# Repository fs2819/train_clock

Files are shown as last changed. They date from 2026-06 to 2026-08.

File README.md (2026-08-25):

# Analog Subway Clock

An analog clock whose hands show the time until the next downtown 1 train arrives at 125th Street (NYC MTA). Runs on a Raspberry Pi Zero 2 W.

## How It Works

The software recomputes hand positions every 10 seconds (`POLL_INTERVAL_SECONDS`), re-fetching the MTA's public GTFS-Realtime feed only when the cache has aged past 30 seconds (`CACHE_TTL_SECONDS`). Arrival times are absolute, so between fetches the hands keep counting down accurately from cached data. The fetch parses the protobuf response and extracts arrival predictions for the southbound 1 train at 125th St (GTFS stop `116S`). The minutes until arrival are mapped to positions on the clock face and driven by three independent stepper motors — one per hand, each following its own train (see *Hand assignment* below).

**Countdown mapping.** 12 o'clock represents a train arriving *now*. A hand for a train `m` minutes away sits `m` minutes *before* 12 — i.e. counterclockwise from the top, exactly like reading a normal clock backwards from the hour:

| Minutes to train | Hand position |
| --- | --- |
| 0 (arriving) | 12 o'clock |
| 1 | the "59" mark (just before 12) |
| 15 | 9 o'clock |
| 30 | 6 o'clock |
| 55 (capped) | 1 o'clock |

As a train approaches, its hand sweeps clockwise up toward 12. Trains beyond `CLOCK_MAX_MINUTES` (55) are pegged at the 1 o'clock cap so a far-out train never wraps past 12 and collides with the "arriving now" position.

**Each hand follows one train.** Hands are *not* pinned to "soonest / second /
third". A hand is handed a specific train (identified by its GTFS trip ID) and
tracks that same train all the way in, sweeping clockwise toward 12. When its
train arrives, that hand takes the soonest train no other hand is showing —
which, since the other two hands are holding the nearer trains, is the
furthest-out train on the dial. So the hand that just reached 12 recycles to
the back of the queue and the other two keep sweeping undisturbed, instead of
all three shuffling up a place on every arrival.

**Hands only ever turn clockwise.** The countdown mapping already sweeps a hand
clockwise as its train approaches, and when a hand switches trains it travels
clockwise to the new position too — the long way round the dial rather than
back-tracking. Over a day every hand rotates in one direction only, like a real
clock.

**Each hand re-homes when its train arrives.** Half-step slip is invisible on
any single move but accumulates over hours, so a clock homed only at startup
has hands well out of place by morning. Instead, the moment a hand's train
leaves the feed — and *before* it swings round to its next train — that one
hand re-homes on its magnet and starts the new sweep from a known 12 o'clock.
The other two hands are untouched and keep tracking their own trains. Homing
sweeps forward, so this respects the clockwise-only rule; the cost is up to one
extra lap (~12 s) that the hand was largely going to make anyway. Set
`REHOME_AFTER_ARRIVAL = False` in `config.py` to go back to homing only at
startup.

At startup all three hands home to 12 o'clock, then take the three soonest
trains by the shortest path (the clockwise-only rule applies to swapping
trains, not to first placement).

This is a Python translation of the [SubwayTimeService](../SubwayTimeService) Go project, stripped of AWS infrastructure (Lambda, DynamoDB, API Gateway) and adapted to run locally on the Pi.

## Project Structure

```
analog_clock/
  config.py             # Station, route, feed URL, polling, GPIO pins, geometry
  mta_feed.py           # Fetches + parses GTFS-Realtime protobuf from MTA
  subway_times.py       # Caching layer, computes minutes-to-arrival
  clock_controller.py   # Maps minutes -> hand angle, drives the 3 steppers
  stepper.py            # StepperHand: half-stepping, homing, position tracking
  main.py               # Entry point — poll loop
  requirements.txt      # Python dependencies
  # Hardware bring-up / diagnostics (run on the Pi):
  test_motor.py         # Spin one motor a full revolution each way
  test_hall.py          # Live readout of one hall sensor
  test_hall_live.py     # Live readout of all three hall sensors at once
```

When `MOTORS_ENABLED = False` (the default, for laptop development), `clock_controller`
just logs what each hand *would* do, so the whole app runs anywhere without GPIO.
Set it to `True` on the Pi to drive the motors.

## Setup (Local / Development)

```bash
# Install uv if you don't have it:
curl -LsSf https://astral.sh/uv/install.sh | sh

uv venv
source .venv/bin/activate
uv pip install -r requirements.txt
uv run main.py
```

No API key is needed — the MTA GTFS-Realtime endpoint is public.

## Deploying to Raspberry Pi Zero 2 W

### 1. OS Setup

Flash **Raspberry Pi OS Lite (64-bit)** onto a microSD card using [Raspberry Pi Imager](https://www.raspberrypi.com/software/). In the imager's settings:
- Enable SSH
- Set your Wi-Fi credentials
- Set a hostname (e.g., `subwayclock.local`)

### 2. SSH In and Install Dependencies

```bash
ssh pi@subwayclock.local

# Update system
sudo apt update && sudo apt upgrade -y

# Install uv
curl -LsSf https://astral.sh/uv/install.sh | sh

# Clone or copy your code to the Pi
# Option A: git clone
# Option B: scp -r analog_clock/ pi@subwayclock.local:~/analog_clock/

cd ~/analog_clock
uv venv
source .venv/bin/activate
uv pip install -r requirements.txt
```

### 3. Test It

```bash
uv run main.py
```

You should see log output like:
```
2026-06-29 23:38:30 [__main__] INFO: Analog subway clock starting
2026-06-29 23:38:30 [mta_feed] INFO: 1 train at 125th St arriving Mon Jun 29 23:48:25 EDT (9.8 min)
2026-06-29 23:38:30 [__main__] INFO: Next 3 trains (min): ['9.8', '21.0', '34.5']
```

With `MOTORS_ENABLED = True`, you'll also see the hands home on startup and then
each move to its train's position:
```
[clock_controller] INFO: Homing 3 hands sequentially...
[stepper] INFO: [hand1] home found (magnet zone 152 steps, centered, offset +0)
...
[clock_controller] INFO: [hand1] 9.8 min -> -58.8°
```

### 4. Run on Boot (systemd)

Create a service file:

```bash
sudo nano /etc/systemd/system/subwayclock.service
```

```ini
[Unit]
Description=Analog Subway Clock
After=network-online.target
Wants=network-online.target

[Service]
Type=simple
User=pi
WorkingDirectory=/home/pi/analog_clock
ExecStart=/home/pi/analog_clock/.venv/bin/python main.py
Restart=always
RestartSec=10

[Install]
WantedBy=multi-user.target
```

```bash
sudo systemctl enable subwayclock
sudo systemctl start subwayclock

# Check logs:
journalctl -u subwayclock -f
```

## Hardware

Three **28BYJ-48** stepper motors (one per hand), each driven by a **ULN2003**
board, plus three hall-effect sensors for homing. Everything runs at 5V/3.3V
directly off the Pi — no external driver chips.

### GPIO wiring (BCM numbering)

Each ULN2003 board: `+` → 5V, `−` → GND, IN1–IN4 → four GPIOs.
Each hall sensor: VCC → **3.3V** (not 5V — keeps the signal pin within the
GPIO's safe range), GND → GND, OUT → one GPIO.

| Hand | Position | IN1 | IN2 | IN3 | IN4 | Hall OUT |
| --- | --- | --- | --- | --- | --- | --- |
| 1 | bottom | GPIO6 | GPIO13 | GPIO19 | GPIO26 | GPIO4 |
| 2 | middle | GPIO12 | GPIO16 | GPIO20 | GPIO21 | GPIO5 |
| 3 | top | GPIO17 | GPIO27 | GPIO22 | GPIO23 | GPIO24 |

All pins are defined in `config.py` (the `HANDS` list) — change them there if you
rewire. Use the breadboard power rails to fan out 5V / 3.3V / GND, since the Pi
header doesn't have enough power pins for three boards plus three sensors. **All
grounds must be common.**

> **Power note.** All three boards share the Pi's 5V pin. To stay within budget,
> the firmware moves and homes **one motor at a time** (~250 mA peak). Don't
> drive all three simultaneously on this power setup, or the Pi can brown out.
> For simultaneous motion, feed the boards from an external 5V supply (grounds
> still tied to the Pi).

### Homing

Each hand carries a magnet; a fixed sensor in the top plate detects it at the
12 o'clock position. On startup — and again for each hand as its train arrives,
unless `REHOME_AFTER_ARRIVAL` is off — `StepperHand.home()`:

1. Sweeps until it finds the magnet's **trigger zone** (an arc, not a point).
2. Measures the zone width and parks at its **center** — the most repeatable
   reference — then applies an optional per-hand `home_offset_steps` fudge to
   land exactly on 12. Budget is two full revolutions, so a wide zone or a
   worst-case start position can never run out.

A re-home that fails mid-run (bad sensor read, magnet knocked loose) is logged
and skipped rather than raised: that hand carries on from its last known,
drifted position and the rest of the clock keeps running.

`HALL_ACTIVE_LEVEL` in `config.py` is the level the sensors read with a magnet
present. These modules are **active-HIGH** (read 1 with a magnet, idle 0).

### Geometry / calibration

- `STEPS_PER_REV = 8192` — **measured**, not assumed. On this hardware, 4096
  half-steps produced only 180° of output rotation, so a full revolution is
  8192. Every minutes→angle conversion depends on this; homing is sensor-based
  and unaffected. (~22.8 steps per degree.)
- `home_offset_steps` (per hand in `HANDS`) nudges that hand clockwise after
  homing to correct a magnet that isn't exactly at 12. The top hand uses -91
  (re-tuned for the current magnets); the others 0. Tune by eye.
- `STEP_DELAY_SECONDS = 0.0015` — the pause between issued half-steps, i.e.
  the speed limit. 1.5 ms works out to ~667 half-steps/s, so a full revolution
  takes `8192 x 0.0015` ≈ **12.3 s** (~5 rpm at the hand). Raised from 1.2 ms
  after the first overnight run drifted badly. This is the single
  most important number for drift: the 28BYJ-48 is driven **open-loop**, with
  no encoder and no acceleration ramp, so if the rotor can't keep up with the
  commanded field it slips poles silently — the code still believes it moved,
  and the hand is permanently offset until the next home. Slower = more torque
  margin. If drift is still building between re-homes, raise it further (up to
  ~2.0 ms) and accept longer sweeps; if a motor audibly buzzes without turning,
  it is already too fast.
- `MINUTES_PER_REV = 60`, `CLOCK_MAX_MINUTES = 55` — the countdown mapping (see
  *How It Works*).

### Bring-up procedure (on the Pi)

Stop the service first so it isn't holding the GPIO: `sudo systemctl stop subwayclock`.

```bash
.venv/bin/python test_motor.py 1      # spin each motor: 1, 2, 3
.venv/bin/python test_hall_live.py    # wave a magnet at each sensor, watch it flip
```

Then set `MOTORS_ENABLED = True` in `config.py`, run `.venv/bin/python main.py`
to watch it home and track trains, and finally `sudo systemctl start subwayclock`.

### GPIO dependencies on the Pi

`gpiozero` + `lgpio` come from apt, **not pip** (the lgpio wheel needs `swig` to
compile and fails under `uv`):

```bash
sudo apt install -y python3-gpiozero python3-lgpio
```

The venv must be able to see them, so create it with system site-packages:

```bash
uv venv --system-site-packages
```

(For an existing venv: set `include-system-site-packages = true` in
`.venv/pyvenv.cfg`.)

### Useful Resources

- `gpiozero` docs: https://gpiozero.readthedocs.io/
- MTA GTFS-Realtime reference: https://api.mta.info/
- Raspberry Pi GPIO pinout: https://pinout.xyz/

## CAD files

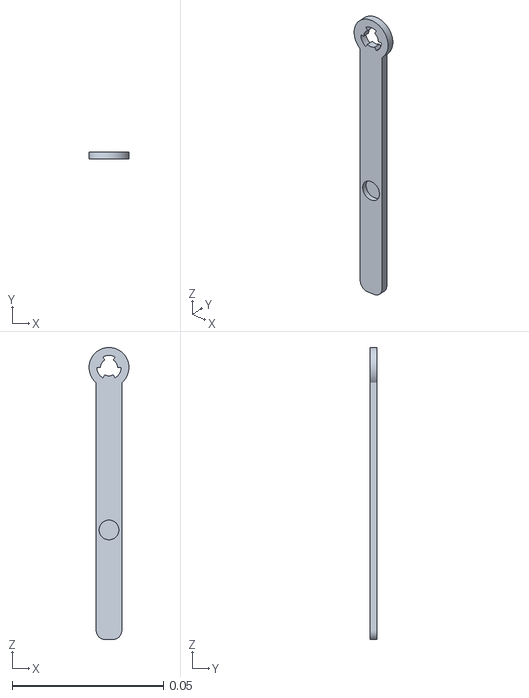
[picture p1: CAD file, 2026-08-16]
3d_printed_parts/Clock V3 Tall/Clock v3_tall - middle needle.stl
0.0132 x 0.0024 x 0.0966

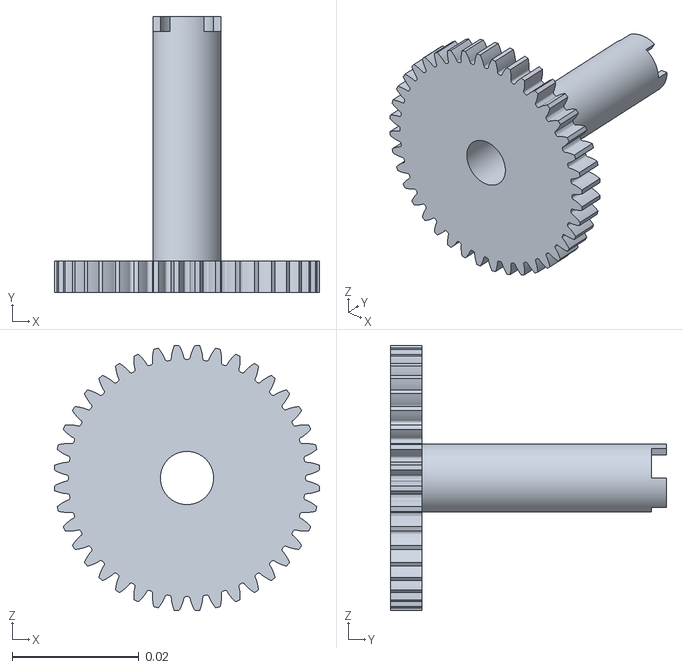
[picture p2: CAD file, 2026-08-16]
3d_printed_parts/Clock V3 Tall/Clock v3_tall - top gear.stl
0.0419 x 0.0436 x 0.0419

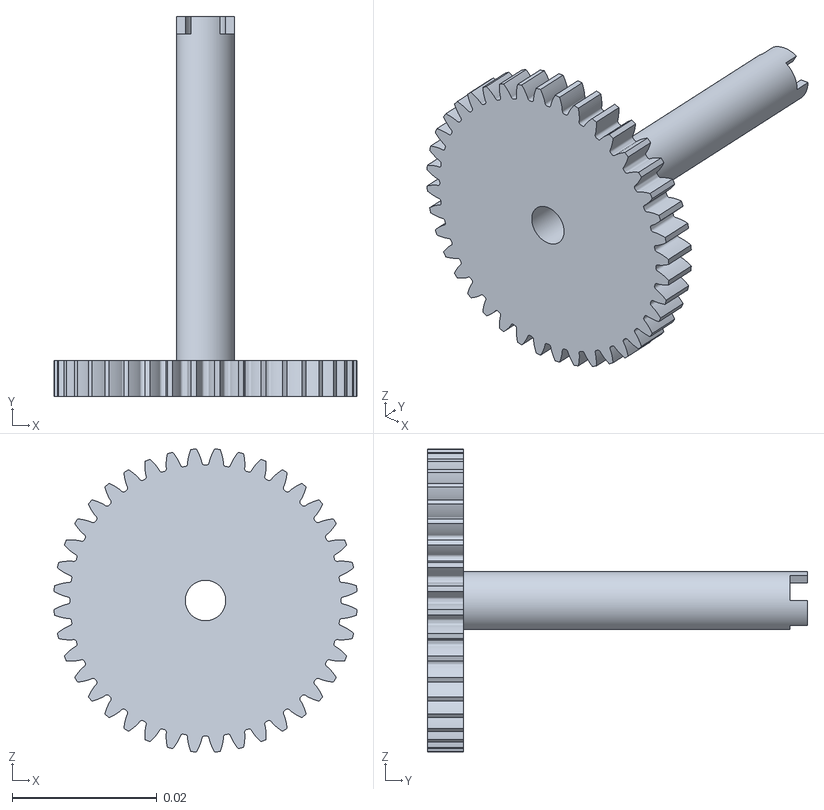
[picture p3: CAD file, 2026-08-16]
3d_printed_parts/Clock V3 Tall/Clock v3_tall - Middle gear.stl
0.0419 x 0.0526 x 0.0419

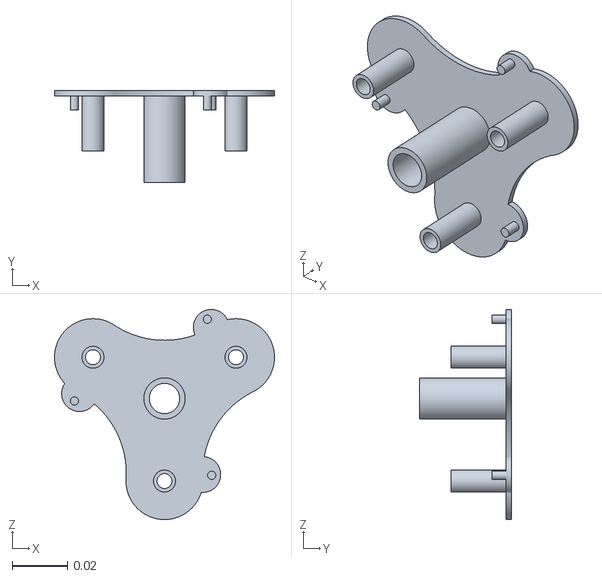
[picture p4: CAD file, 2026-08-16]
3d_printed_parts/Clock V3 Tall/Clock v3_tall - top plate.stl
0.08 x 0.0334 x 0.0764

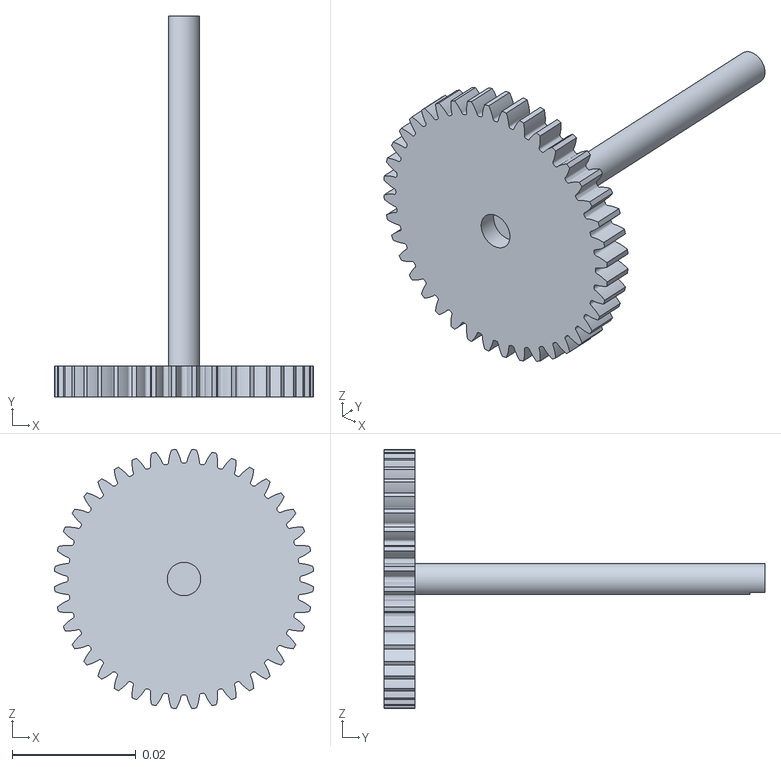
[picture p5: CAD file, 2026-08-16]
3d_printed_parts/Clock V3 Tall/Clock v3_tall - Bottom gear.stl
0.0419 x 0.0616 x 0.0419

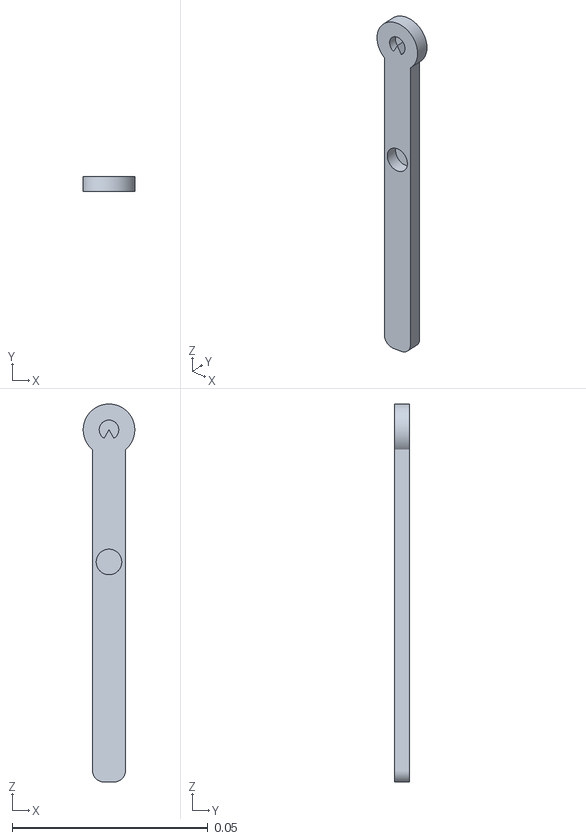
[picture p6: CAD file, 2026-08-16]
3d_printed_parts/Clock V3 Tall/Clock v3_tall - top needle.stl
0.0132 x 0.0039 x 0.0966

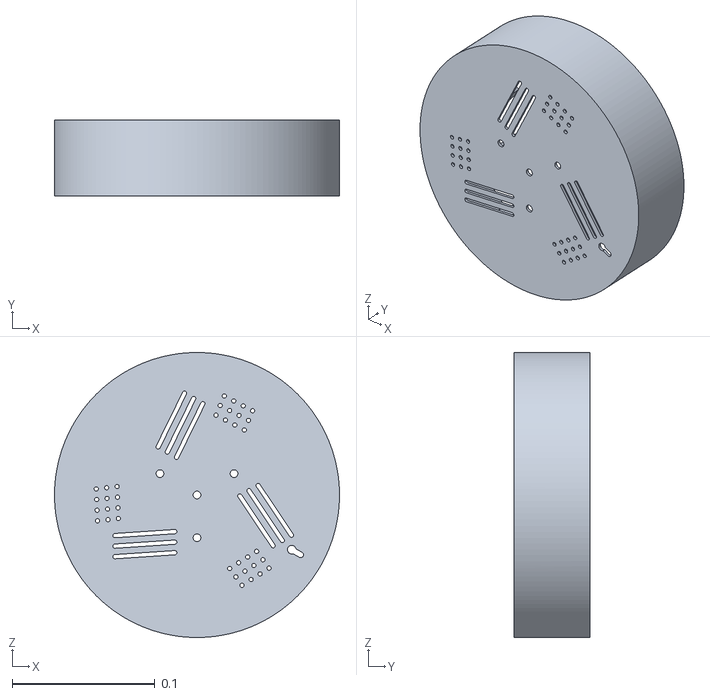
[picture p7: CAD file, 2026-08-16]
3d_printed_parts/Clock V3 Tall/Clock v3_tall - Shell.stl
0.2 x 0.053 x 0.2

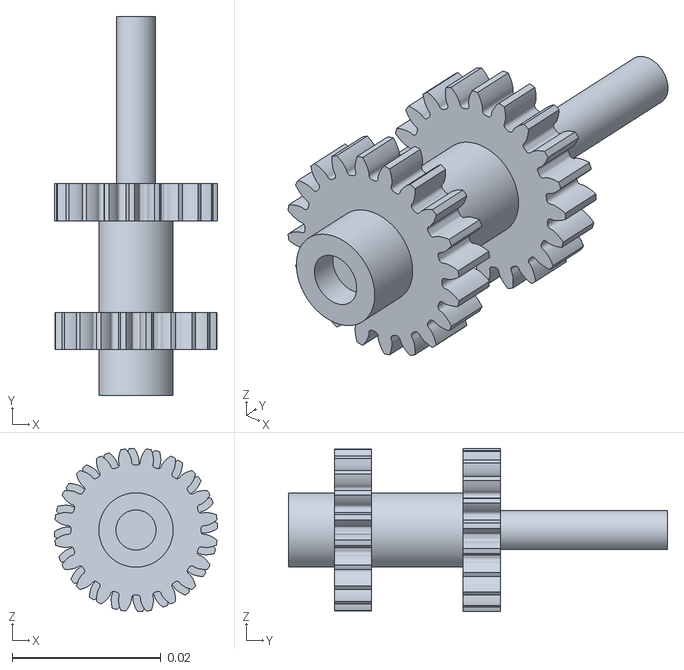
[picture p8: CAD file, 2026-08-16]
3d_printed_parts/Clock V3 Tall/Clock v3_tall - transfer gear 2.stl
0.022 x 0.051 x 0.022

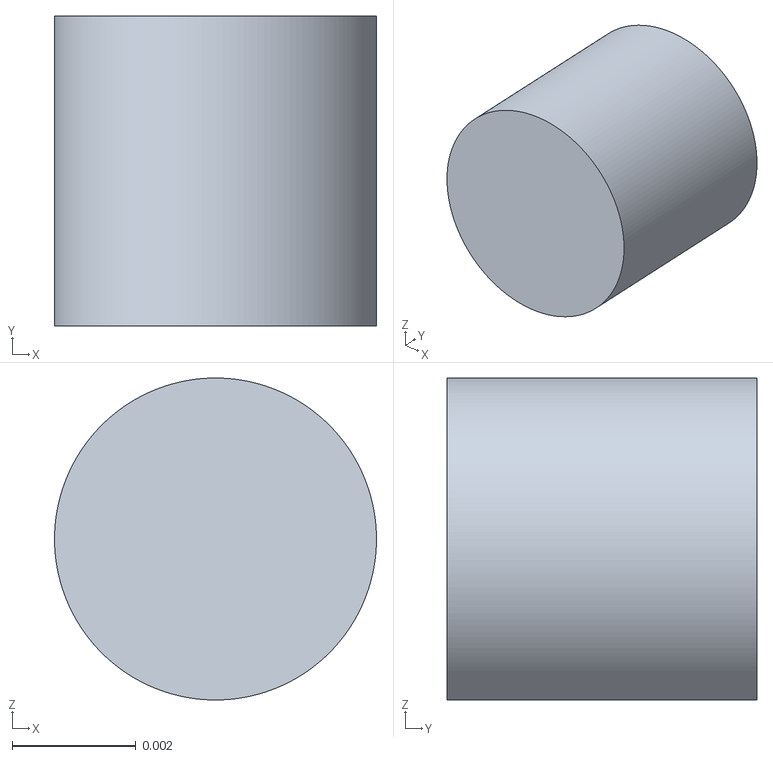
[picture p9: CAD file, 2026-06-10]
3d_printed_parts/Clock V3 Tall/Clock v3_tall - pin.stl
0.0052 x 0.005 x 0.0052

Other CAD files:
3d_printed_parts/Clock V3 Tall/Clock v3_tall - bottom needle.stl
3d_printed_parts/Clock V3 Tall/Clock v3_tall - Transfer gear 1.stl
3d_printed_parts/Clock V3 Tall/Clock v3_tall - transfer gear 3.stl
3d_printed_parts/Clock V3 Tall/Clock v3_tall - pin (1).stl
3d_printed_parts/Clock V3 Tall/Clock v3_tall - pin (2).stl
3d_printed_parts/Clock V3 Tall/Clock v3_tall - pin (3).stl

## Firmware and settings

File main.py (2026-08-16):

"""Entry point for the analog subway clock.

Polls MTA data and updates the clock hands on a loop.
"""

import logging
import signal
import sys
import time

from config import NUM_HANDS, POLL_INTERVAL_SECONDS, LOG_LEVEL
from subway_times import get_upcoming_trains
from clock_controller import update_clock_hands, shutdown as shutdown_clock

logging.basicConfig(
    level=getattr(logging, LOG_LEVEL),
    format="%(asctime)s [%(name)s] %(levelname)s: %(message)s",
)
logger = logging.getLogger(__name__)

running = True


def handle_shutdown(signum, frame):
    global running
    logger.info("Shutting down...")
    running = False


signal.signal(signal.SIGINT, handle_shutdown)
signal.signal(signal.SIGTERM, handle_shutdown)


def main():
    logger.info("Analog subway clock starting")
    logger.info("Polling every %d seconds", POLL_INTERVAL_SECONDS)

    while running:
        try:
            # Pass the whole queue, not just NUM_HANDS of it: the controller
            # assigns hands to individual trains and a hand whose train has
            # just arrived picks up one from further down the list.
            upcoming = get_upcoming_trains()
            display = [f"{t.minutes:.1f}" for t in upcoming[:NUM_HANDS]]
            logger.info("Next %d trains (min): %s", NUM_HANDS, display)

            update_clock_hands(upcoming)

        except Exception:
            logger.exception("Error in main loop")

        time.sleep(POLL_INTERVAL_SECONDS)

    shutdown_clock()
    logger.info("Goodbye")


if __name__ == "__main__":
    main()

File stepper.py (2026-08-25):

"""Driver for a single 28BYJ-48 stepper motor (via ULN2003) with a hall-effect
home sensor.

One ``StepperHand`` owns four GPIO output pins (the ULN2003 IN1..IN4) and one
input pin (the hall sensor). It tracks absolute position in half-steps from the
home position, can home itself by sweeping until the sensor triggers, and moves
to a target angle by the shorter of the two directions.

Uses gpiozero (backed by lgpio on the Pi Zero 2 W). gpiozero is only imported
when a hand is actually constructed, so this module is importable on a laptop
with no GPIO — handy for editing/linting off-Pi.
"""

import logging
import time

logger = logging.getLogger(__name__)

# Half-step sequence for the 28BYJ-48. Eight states, energising one or two of
# the four coils at a time. Driving the sequence forward turns the shaft one
# way; reversed, the other. Half-stepping gives smoother motion and better
# positional resolution than full-stepping.
HALF_STEP_SEQUENCE = [
    (1, 0, 0, 0),
    (1, 1, 0, 0),
    (0, 1, 0, 0),
    (0, 1, 1, 0),
    (0, 0, 1, 0),
    (0, 0, 1, 1),
    (0, 0, 0, 1),
    (1, 0, 0, 1),
]


class StepperHand:
    def __init__(
        self,
        in_pins,
        hall_pin,
        steps_per_rev,
        step_delay,
        hall_active_level,
        homing_max_steps,
        name="hand",
        home_offset_steps=0,
    ):
        # Import here so the module loads fine on a non-Pi machine.
        from gpiozero import DigitalInputDevice, DigitalOutputDevice

        self.name = name
        self.steps_per_rev = steps_per_rev
        self.step_delay = step_delay
        self.hall_active_level = hall_active_level
        self.homing_max_steps = homing_max_steps
        # Mechanical fudge: after centering on the magnet zone, step this many
        # half-steps before declaring 0. Corrects a hand whose magnet isn't
        # exactly at the true 12 o'clock. Positive = clockwise (forward).
        self.home_offset_steps = home_offset_steps

        self._coils = [DigitalOutputDevice(pin) for pin in in_pins]

        # pull_up=True keeps a floating sensor from reading garbage. These
        # modules are active-HIGH (read HIGH when a magnet is present); the
        # caller's hall_active_level encodes that.
        self._hall = DigitalInputDevice(hall_pin, pull_up=True)

        self._seq_index = 0          # where we are in HALF_STEP_SEQUENCE
        self._position = 0           # absolute half-steps from home (0..steps_per_rev-1)
        self._homed = False

    # -- low level ---------------------------------------------------------

    def _apply(self, pattern):
        for coil, value in zip(self._coils, pattern):
            coil.value = value

    def release(self):
        """De-energise all coils. The motor holds position via gear friction
        and stops drawing current (and stops getting warm)."""
        self._apply((0, 0, 0, 0))

    def _step(self, direction):
        """Advance one half-step. direction is +1 or -1."""
        self._seq_index = (self._seq_index + direction) % len(HALF_STEP_SEQUENCE)
        self._apply(HALF_STEP_SEQUENCE[self._seq_index])
        self._position = (self._position + direction) % self.steps_per_rev
        time.sleep(self.step_delay)

    def step_many(self, steps):
        """Move `steps` half-steps. Positive = forward, negative = reverse."""
        direction = 1 if steps >= 0 else -1
        for _ in range(abs(steps)):
            self._step(direction)
        self.release()

    @property
    def _hall_triggered(self):
        # gpiozero DigitalInputDevice.value is 1 when the pin reads HIGH.
        level = 1 if self._hall.value else 0
        return level == self.hall_active_level

    # -- homing ------------------------------------------------------------

    def home(self):
        """Find the 0 position using the hall sensor, then define it as 0.

        The magnet covers an arc of the revolution (the "trigger zone"), not a
        single point. To get a repeatable home regardless of where we start or
        how wide that zone is, we:

          1. If we start inside the zone, step forward until we exit it (so the
             next entry is a clean rising edge).
          2. Sweep forward until we re-enter the zone (the leading edge).
          3. Keep stepping through the zone to its far edge, then set home to
             the CENTER of the zone — the most repeatable reference point.

        Budget is two full revolutions so a wide trigger zone plus a worst-case
        starting position can never run out prematurely. Raises RuntimeError if
        the sensor never triggers (bad wiring, missing magnet, or wrong
        HALL_ACTIVE_LEVEL)."""
        logger.info("[%s] homing...", self.name)
        budget = 2 * self.steps_per_rev

        # Remember where the step count *claimed* we were, so a re-home can
        # report how wrong that claim turned out to be.
        start_position = self._position
        was_homed = self._homed

        # 1. Exit the zone if we start inside it.
        steps = 0
        while self._hall_triggered and steps < budget:
            self._step(1)
            steps += 1

        # 2. Find the leading edge (first step where the magnet appears).
        while not self._hall_triggered and steps < budget:
            self._step(1)
            steps += 1
        if steps >= budget:
            self.release()
            raise RuntimeError(
                f"[{self.name}] homing failed: hall sensor never triggered in "
                f"{budget} steps — check wiring, magnet, and HALL_ACTIVE_LEVEL"
            )

        # 3. Measure the zone width, then back up to its center.
        zone = 0
        while self._hall_triggered and zone < self.steps_per_rev:
            self._step(1)
            zone += 1
        self.step_many(-(zone // 2))  # land on the middle of the magnet

        # 4. Apply the mechanical home offset so 0 lands on true 12 o'clock.
        if self.home_offset_steps:
            self.step_many(self.home_offset_steps)

        self.release()

        # 5. Compare distance actually travelled against the distance the step
        # count predicted. On a re-home the gap is accumulated open-loop error
        # since the last home — the thing STEP_DELAY_SECONDS is tuned against.
        # Positive = the hand was lagging (lost steps); negative = ran ahead.
        drift = None
        if was_homed:
            travelled = steps + zone - (zone // 2) + self.home_offset_steps
            expected = (0 - start_position) % self.steps_per_rev
            drift = (travelled - expected) % self.steps_per_rev
            if drift > self.steps_per_rev // 2:
                drift -= self.steps_per_rev

        self._position = 0
        self._seq_index = 0
        self._homed = True
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

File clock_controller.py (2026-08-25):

"""Clock controller — maps train arrival minutes to physical hand positions.

When MOTORS_ENABLED is True, this drives three 28BYJ-48 steppers (one per hand)
to point at the arrival time of each of the next three trains. When False, it
just logs what each hand would do, so the rest of the app can be developed and
run anywhere.

Mapping: a train `m` minutes away points at angle (m / CLOCK_MAX_MINUTES) * 360,
measured clockwise from the home position (12 o'clock = 0 minutes). Trains
beyond CLOCK_MAX_MINUTES are pegged at the max. Hands with no data park at home.

Hand assignment: each hand follows ONE specific train (tracked by GTFS trip ID)
for that train's whole approach, rather than being pinned to "soonest" /
"second" / "third". When a hand's train arrives, that hand takes the soonest
train no other hand is showing — which, since the other hands are holding the
nearer trains, is the furthest-out train on the dial. So a hand that reaches 12
o'clock recycles to the back of the queue and the other hands keep sweeping
undisturbed, instead of all three shuffling up a place on every arrival.

Direction: a hand always travels CLOCKWISE when it switches trains, even though
that means crossing most of the dial. Combined with the countdown mapping (which
already sweeps a hand clockwise as its train approaches), each hand therefore
only ever advances clockwise, like a real clock.

Drift: half-step slip is invisible on any one move but accumulates over hours,
so a hand homed only at startup is noticeably off by morning. Each hand
therefore RE-HOMES at the one moment it is free — after its train has arrived,
before it swings round to its next one — correcting that hand without
disturbing the two still tracking their own trains. See REHOME_AFTER_ARRIVAL.

Movement is sequential (one motor at a time). With all three boards powered
from the Pi's 5V pin this keeps peak current to a single motor (~250 mA),
avoiding brownouts. If you later add an external 5V supply you can parallelise.
"""

import logging

from config import (
    CLOCK_MAX_MINUTES,
    HANDS,
    HALL_ACTIVE_LEVEL,
    HOMING_MAX_STEPS,
    MINUTES_PER_REV,
    MOTORS_ENABLED,
    NO_SERVICE_ANGLE,
    NUM_HANDS,
    REHOME_AFTER_ARRIVAL,
    STEP_DELAY_SECONDS,
    STEPS_PER_REV,
)
from subway_times import UpcomingTrain

logger = logging.getLogger(__name__)

# Built lazily on first use so importing this module never touches GPIO.
_hands = None

# Which train (GTFS trip ID) each hand is currently following. None = no train.
# Persisted across polls; this is what lets a hand stay with its own train.
_hand_trip_ids: list[str | None] = [None] * NUM_HANDS


def _get_hands():
    """Construct and home the three steppers once, on first call."""
    global _hands
    if _hands is not None:
        return _hands

    from stepper import StepperHand

    hands = [
        StepperHand(
            in_pins=cfg["in_pins"],
            hall_pin=cfg["hall_pin"],
            steps_per_rev=STEPS_PER_REV,
            step_delay=STEP_DELAY_SECONDS,
            hall_active_level=HALL_ACTIVE_LEVEL,
            homing_max_steps=HOMING_MAX_STEPS,
            name=f"hand{i + 1}",
            home_offset_steps=cfg.get("home_offset_steps", 0),
        )
        for i, cfg in enumerate(HANDS)
    ]

    # Home one hand at a time. With all boards on the Pi's 5V rail this keeps
    # peak draw to a single motor; it also makes a stall obvious (you see which
    # hand's homing line never prints its "home found" follow-up).
    logger.info("Homing %d hands sequentially...", len(hands))
    for hand in hands:
        hand.home()
    logger.info("All hands homed.")

    _hands = hands
    return _hands


def _rehome(hand) -> None:
    """Re-find 12 o'clock for one hand, mid-run.

    Called when a hand's train has arrived and it is about to travel the long
    way round to its next train. ``home()`` sweeps forward, so this keeps the
    clockwise-only rule; the cost is up to one extra lap (~12 s) that the hand
    was largely going to make anyway.

    A failure here is logged, not raised: the hand keeps its old (drifted)
    position and the clock carries on, rather than the whole poll dying on one
    bad sensor read.
    """
    logger.info("[%s] train arrived — re-homing before its next train", hand.name)
    try:
        hand.home()
    except Exception:
        logger.exception(
            "[%s] re-home failed — carrying on from last known position", hand.name
        )


def _assign_trains(upcoming: list[UpcomingTrain]) -> list[UpcomingTrain | None]:
    """Work out which train each hand should show, and remember it.

    Hands keep the train they are already following for as long as it is still
    in the feed. Any hand whose train has gone (arrived, or cancelled) takes the
    soonest train nobody else is showing.

    Returns NUM_HANDS entries, each an UpcomingTrain or None when there simply
    aren't enough trains to go round.
    """
    global _hand_trip_ids

    by_id = {t.trip_id: t for t in upcoming}

    # A hand whose train is still coming keeps it.
    assigned: list[UpcomingTrain | None] = [
        by_id.get(trip_id) if trip_id is not None else None
        for trip_id in _hand_trip_ids
    ]

    # Trains no hand is showing, soonest first.
    claimed = {t.trip_id for t in assigned if t is not None}
    unclaimed = [t for t in upcoming if t.trip_id not in claimed]

    # Each free hand picks up the soonest of those.
    for i, current in enumerate(assigned):
        if current is None and unclaimed:
            assigned[i] = unclaimed.pop(0)

    _hand_trip_ids = [t.trip_id if t is not None else None for t in assigned]
    return assigned


def _angle_for_minutes(minutes: float) -> float:
    """Clock-face angle (degrees) for a train this many minutes away.

    Countdown style: 12 o'clock is the train arriving NOW, and a hand sits
    `minutes` BEFORE 12 — i.e. counterclockwise from the top. As the train
    approaches, the hand sweeps clockwise up toward 12.

      0 min  -> 12 o'clock (0°/360°)
      1 min  -> 59 on the dial (354°)
      15 min -> 9 o'clock (270°)
      30 min -> 6 o'clock (180°)
      55 min -> 1 o'clock (30°)

    Minutes are capped at CLOCK_MAX_MINUTES so a far-out train never wraps
    past 12 and collides with the "arriving now" position. The returned angle
    may be negative; callers take it mod 360.
    """
    capped = min(minutes, CLOCK_MAX_MINUTES)
    return -capped / MINUTES_PER_REV * 360.0
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

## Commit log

2026-06-10 added 3d printed parts
    [Clock V2 - Bottom gear.stl, Clock V2 - Bottom separator.stl, Clock V2 - Middle gear.stl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]
2026-06-30 Drive three stepper hands with hall-sensor homing
    Replace the clock_controller stub with a working driver for three 28BYJ-48
    steppers (one per hand) plus hall-effect homing:
    - stepper.py: StepperHand class — half-stepping, absolute position tracking,
    shortest-path moves, and homing that centers on the magnet's trigger zone
    with a per-hand offset to land on true 12 o'clock.
    - clock_controller.py: countdown mapping — a train m minutes away points m
    minutes *before* 12 (12 = arriving now), sweeping up to 12 as it approaches.
    Drives the motors sequentially to stay within the Pi's 5V budget; falls back
    to log-only when MOTORS_ENABLED is False.
    - config.py: GPIO pins, geometry, and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
    [Clock V2 - Lid.stl, Clock V2 - top gear.stl, Clock V2 - top plate.stl]
2026-06-30 Handle no downtown service at the stop
    - Hands with no train now park at a distinct no-service position (3 o'clock,
    NO_SERVICE_ANGLE=90°) instead of 12, which was ambiguous with a 0-min train.
    All three at 3 o'clock = no downtown 1 trains stopping at 125th St.
    - mta_feed skips stop-time updates marked SKIPPED in GTFS-Realtime, so a train
    routed express past 125th isn't counted as an arrival.
    [clock_controller.py, config.py, mta_feed.py]
2026-08-16 Track one train per hand and rotate clockwise only
    Hands were pinned to queue positions (soonest/second/third), so every
    arrival shuffled all three at once. Each hand now follows one specific
    train by GTFS trip ID until that train arrives, then takes the soonest
    train no other hand is showing -- which, since the other hands hold the
    nearer trains, is the furthest out on the dial. A hand reaching 12
    o'clock therefore recycles to the back of the queue while the others
    keep sweeping undisturbed.
    Hands also only ever advance clockwise: the countdown mapping already
    sweeps a hand clockwise as its train approaches, and switching trains
    now travels clockwise too rather than taking the shorter path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
    [clock_controller.py, config.py, hall_watch.py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]
2026-08-16 Replace Clock V2 printed parts with V3 Tall
    Drops the V2 STLs and adds the V3 Tall set, with each part renamed from
    "Clock V2 - ..." to "Clock v3_tall - ...".
    [Clock V2 - Bottom gear.stl, Clock V2 - Bottom separator.stl, Clock V2 - Lid.stl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]
2026-08-25 Re-home each hand when its train arrives
    The first overnight run left all three hands well out of place even though
    the software was healthy: position is dead-reckoned from issued step counts,
    so silent slip accumulates all night with only the startup home to correct it.
    Each hand now re-homes at the one moment it is idle — after its train has
    left the feed, before it swings round to the next one. The other two hands
    keep tracking undisturbed. home() sweeps forward, so this respects the
    clockwise-only rule, costing up to one extra lap (~12 s) the hand was largely
    going to make anyway. A failed re-home is logged, not raised, so one bad
    sensor read doesn't take down the poll.
    Also raise ST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
    [clock_controller.py, config.py, stepper.py]
2026-08-25 Correct re-home lap estimate for the slower step delay
    A lap is ~12 s at 1.5 ms/step, not the ~10 s these two comments carried over
    from 1.2 ms. README was already updated.
    [clock_controller.py, config.py]
